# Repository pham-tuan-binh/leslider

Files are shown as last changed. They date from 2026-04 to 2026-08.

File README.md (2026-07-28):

<h1 align="center">LeSlider</h1>

<p align="center">
  
  
  
  
  
</p>

<p align="center">
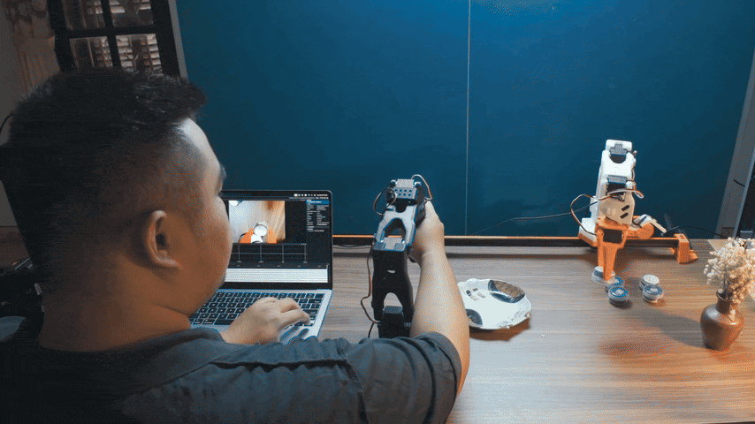
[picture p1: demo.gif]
leslider rig running
  
</p>

<p align="center"><b>Mount an SO-101 on a 7th-motor slider.</b></p>

One teleop mode ships for the full rig: the SO-101 leader mirrors the follower
arm (including the base), while the keyboard drives the linear slider. Optional
cameras on the leader feed Rerun when you use `uv run leslider-teleoperate`. Print the
parts, run `uv sync`, and you have a 7-DOF arm with linear travel that
records datasets and runs policies the same way a stock SO-101 does.

The slider ships in two flavors. The default `so101_slider_follower` drives the
slider in **velocity** mode (`slider.vel`, continuous rotation). A second variant,
`so101_slider_pos_follower`, drives it in **extended (multi-turn) position** mode so
the slider becomes a unified normalized `slider.pos` joint just like the arm — see
[section 10](#10-position-mode-slider-extended-position).

---

## Build flow

1. [Bill of Materials](#1-bill-of-materials): what to buy
2. [3D-printed parts](#2-3d-printed-parts): what to print
3. [Assembly](#3-assembly): wiring and mounting
4. [Install the plugins](#4-install-the-plugins)
5. [Set the slider motor ID](#5-set-the-slider-motor-id)
6. [Calibrate](#6-calibrate)
7. [Run it](#7-run-it): full-rig teleop and live view
8. [Record datasets](#8-record-datasets)
9. [Config reference](#9-config-reference)
10. [Position-mode slider (extended position)](#10-position-mode-slider-extended-position)
11. [Troubleshooting](#11-troubleshooting)

---

## 1. Bill of Materials

Parts you need **in addition to a stock SO-101 kit**. The kit already ships
the six arm STS3215s, brackets, gripper, USB-to-TTL adapter, 12 V PSU, and
cabling, all of which the slider rig reuses.

| Item | Qty | Notes |
| --- | --- | --- |
| [STS3215 Feetech servo](https://www.waveshare.com/wiki/ST3215_Servo) (slider drive) | 1 | same model as the arm motors, shares the SO-101 bus. Bus cable for the slider is included with the servo. |
| [2020 V-slot aluminum extrusion](https://vi.aliexpress.com/item/1005004784760394.html) | 1 | any length sized to your reach (300 to 500 mm is typical) |
| [Gantry plate with V-wheels](https://vi.aliexpress.com/i/32985227943.html?gatewayAdapt=glo2vnm) | 1 | rides the 2020 extrusion as the carriage |
| M3 bolts, 20 mm or longer | 4 | |
| M5 bolts, 10 mm or longer, plus matching M5 nuts | 2 sets | |
| M5 bolts (12 to 16 mm), plus M5 drop-in T-nuts sized for the 2020 V-slot | 2 sets | mounts the legs to the extrusion. M5 is the standard thread for 2020 T-nuts. |

---

## 2. 3D-printed parts

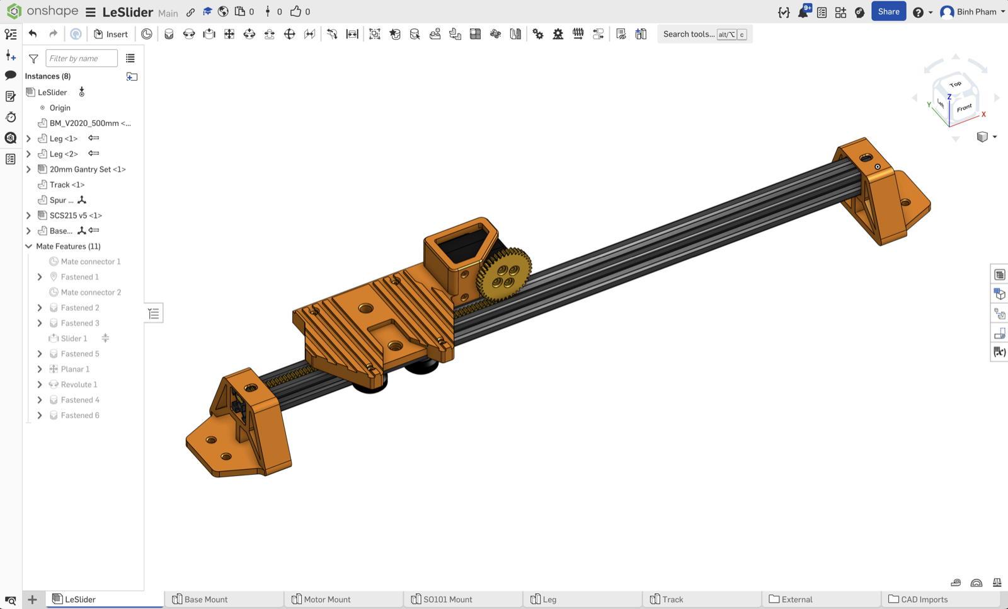
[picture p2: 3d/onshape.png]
Onshape model


Source CAD lives on [Onshape](https://cad.onshape.com/documents/7799de322e403a9ba91b0f22/w/05147a3d6feb75b69c2b0fa5/e/832d406a94d20085fd4bee6e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),
where you can spin the assembly, take measurements, or fork it for your own
extrusion length, motor mount, or leg geometry. Exported printable files
live in `3d/`.

The fastest path is `3d/full_print.3mf`: open it in Bambu Studio (or any
slicer that imports `.3mf`) and the whole plate is laid out for you.
Individual parts also live in `3d/separate_components/` if you want to
slice them on a smaller bed or print them one at a time.

Per rig, you need:

| File | Qty | Notes |
| --- | --- | --- |
| `separate_components/leg.3mf` | 2 | one at each end of the V-slot extrusion |
| `separate_components/base_mount.3mf` | 1 | sits on the gantry plate; holds the SO-101 base and the slider servo |
| `separate_components/pinion.3mf` | 1 | press-fits onto the slider servo's output gear; engages the rack track |
| `separate_components/track.3mf` | as needed | drop-in rack segments for the V-slot. Each segment is 20 mm long; print enough to span your extrusion and trim the last one if it overruns. |

---

## 3. Assembly

1. **Print the parts.** Use `3d/full_print.3mf` for the all-in-one plate, or
   slice the individual files in `3d/separate_components/`. Quantities: 2
   legs, 1 base mount, 1 pinion, plus enough 20 mm track segments to span
   your extrusion (cut the last one to length if it overruns).
2. **Lay the rack track.** Slide the printed track segments into the
   top-facing channel of the V-slot extrusion. They sit directly under
   where the base mount will land, so the slider servo's pinion drops
   straight into the rack.
3. **Slide the gantry plate** onto the V-slot so its V-wheels engage the
   side channels. Do this before the legs go on, so the plate can slide in
   from one open end.
4. **Bolt the legs** to each end of the extrusion. Per leg: one M5 bolt
   through the leg into one drop-in M5 T-nut sitting in the V-slot's side
   channel.
5. **Mount the base plate to the gantry.** The gantry plate has two M5
   holes spaced 20 mm apart; align the base mount over them and secure with
   two M5 bolts plus M5 nuts on the underside.
6. **Bolt the SO-101 base** to the base mount with four M3 bolts (20 mm or
   longer) through the four screw holes in the SO-101's base bracket.
7. **Drop the slider STS3215** into the cutout on the base mount, slide the
   printed pinion onto the servo's output gear so it engages the rack
   track, and secure the servo with the screws that ship in its package.
8. **Daisy-chain the slider** onto the SO-101 bus: unplug the cable that
   runs from the base yaw to the USB-TTL controller, plug it into the slider
   STS3215, then run a new cable from the slider to the controller. The
   order on the bus is base yaw → slider → controller. All seven motors share
   one bus back to the host; only the IDs matter for addressing.
9. **Power.** Use the same power supply that comes with your SO101.

---

## 4. Install the plugins

This repo is a [uv](https://docs.astral.sh/uv/) workspace: the root
`pyproject.toml` lists each workspace package explicitly, so a single `uv sync`
installs `lerobot` along with every workspace package (robot plugin, teleop
plugin, and `leslider_teleoperate`) editable into one
shared `.venv`.

```bash
git clone https://github.com/pham-tuan-binh/leslider
cd leslider
uv sync
```

That's it. There is nothing on PyPI for these plugins; the workspace is the
only install path. Run lerobot CLIs through `uv run` so they pick up the
workspace venv automatically:

```bash
uv run lerobot-teleoperate ...
uv run lerobot-calibrate ...
uv run lerobot-record ...
```

Or activate the venv once per shell with `source .venv/bin/activate` and
call the same commands directly. Editing any file under `packages/*/src/`
takes effect on the next import; no re-sync needed.

LeRobot's plugin loader picks up the packages by name prefix
(`lerobot_robot_*` / `lerobot_teleoperator_*`), so once the venv is active you
should see `so101_slider_follower` and `so101_with_slider_leader` (velocity mode),
plus `so101_slider_pos_follower` and `so101_with_slider_pos_leader` (extended-position
mode), as `--robot.type` / `--teleop.type` choices on every CLI invocation.

For teleoperation with **follower plus leader camera streams** in Rerun, use
`uv run leslider-teleoperate` (same flags as `uv run lerobot-teleoperate`, plus it merges
`teleop.cameras` into the logged observation). Plain `uv run lerobot-teleoperate` only
shows the robot's own `robot.cameras`.

### Find your serial ports

LeRobot ships a port-finder. Unplug the arm it asks about, press ENTER,
plug it back in. Run it once per arm:

```bash
uv run lerobot-find-port
```

Note the paths it prints (`/dev/tty.usbmodem...` on macOS,
`/dev/ttyACM...` on Linux). You'll paste them into the configs below or
pass them on the command line.

### Quick runs with a config file

Every LeRobot CLI accepts `--config_path=<file.yaml>` (parsed by
[draccus](https://github.com/dlwh/draccus)), so once you write a YAML
profile you stop retyping flags. The repo ships ready-made profiles in
`configs/`:

| Profile | What it runs |
| --- | --- |
| `configs/teleop_full_rig.yaml` | SO-101 leader mirrors arm; arrows drive slider (velocity) |
| `configs/calibrate_follower.yaml` | Calibrate the SO-101 + slider follower (velocity) |
| `configs/calibrate_leader.yaml` | Calibrate the stock SO-101 leader |
| `configs/record.yaml` | Record a dataset with the full rig |
| `configs/teleop_full_rig_pos.yaml` | Extended-position rig; arrows drive `slider.pos` |
| `configs/calibrate_follower_pos.yaml` | Calibrate the extended-position follower |

Edit each profile once with your ports and calibration IDs, then:

```bash
uv run lerobot-teleoperate --config_path=configs/teleop_full_rig.yaml
uv run leslider-teleoperate --config_path=configs/teleop_full_rig.yaml
uv run lerobot-calibrate   --config_path=configs/calibrate_follower.yaml
uv run lerobot-calibrate   --config_path=configs/calibrate_leader.yaml
uv run lerobot-record      --config_path=configs/record.yaml
```

Override any field at the CLI for a one-off:

```bash
uv run lerobot-teleoperate --config_path=configs/teleop_full_rig.yaml \
    --robot.port=/dev/tty.usbmodemSOMETHINGELSE
```

The long-form invocations in the sections below show exactly which flags
each profile sets, in case you need to tweak.

---

## 5. Set the slider motor ID

The slider motor must live on a Feetech ID outside 1..6 (default: 7). The
upstream `lerobot-setup-motors` rejects our `so101_slider_follower` type
(its device whitelist is hardcoded), so the repo ships a small wrapper:

```bash
uv run scripts/setup_slider_motor.py \
    --port=/dev/tty.usbmodemFOLLOWER \
    --slider-id=7
```

Connect **only the slider motor** to the controller before pressing ENTER.
The script opens a minimal bus with just the slider so no other motors are
scanned or disturbed.

After that, daisy-chain everything back together.

---

## 6. Calibrate

Only the arm joints need calibration. The slider runs in continuous-rotation
velocity mode and is skipped.

```bash
uv run lerobot-calibrate \
    --robot.type=so101_slider_follower \
    --robot.port=/dev/tty.usbmodemXXXX \
    --robot.id=my_arm
```

This is the stock SO-101 calibration (middle pose, range-of-motion sweep)
against IDs 1..6. The result lands in
`~/.cache/huggingface/lerobot/calibration/robots/so101_slider_follower/my_arm.json`.

If you also use the SO-101 leader arm for teleop, calibrate it once:

```bash
uv run lerobot-calibrate \
    --teleop.type=so101_leader \
    --teleop.port=/dev/tty.usbmodemLEADER \
    --teleop.id=my_leader
```

---

## 7. Run it

Use `so101_with_slider_leader`. All six leader joints, **including**
`shoulder_pan`, are copied to the follower as `*.pos` goals. The linear slider
is driven only from the keyboard as `slider.vel` (same feel as the old
keyboard-only mode).

```bash
uv run lerobot-teleoperate \
    --robot.type=so101_slider_follower \
    --robot.port=/dev/tty.usbmodemFOLLOWER \
    --robot.id=my_arm \
    --teleop.type=so101_with_slider_leader \
    --teleop.port=/dev/tty.usbmodemLEADER \
    --teleop.id=my_leader
```

| Key | Effect |
| --- | --- |
| Leader arm | Mirrors the follower (base, lift, elbow, wrist, gripper). |
| Left / Right arrow | Hold to run the slider negative / positive at the current cruise speed. |
| Up / Down arrow | Tap to raise / lower cruise speed (`speed_increment`, bounded). |
| Space | Hold to command zero slider velocity (emergency stop). |
| ESC | Disconnect |

### Live view: follower + teleop cameras in Rerun

When you run `uv run lerobot-teleoperate` with `display_data: true` in the config (or
`--display_data=true`) it logs the robot observation only. To also stream
**leader-side** USB cameras, run the bundled wrapper and add `teleop.cameras`
in YAML (same shape as `robot.cameras`):

Set `display_data: true` in `configs/teleop_full_rig.yaml` (top level), or pass
`--display_data=true` on the CLI to override.

```bash
uv run leslider-teleoperate --config_path=configs/teleop_full_rig.yaml
```

Uncomment `robot.cameras` / `teleop.cameras` in `configs/teleop_full_rig.yaml` as needed.
Follower cameras (`robot.cameras`) show up as `observation.<name>` everywhere.
`teleop.cameras` is only merged when you use **`uv run leslider-teleoperate`** with
`display_data: true` (Rerun under `observation.teleop.<name>`). **`uv run lerobot-record`**
does not read teleop cameras—see [section 8](#8-record-datasets): put extra USB views on
`robot.cameras` if you want them in the dataset.

---

## 8. Record datasets

Same `uv run lerobot-record` invocation as a stock SO-101, just point at the new
robot type and `so101_with_slider_leader`:

```bash
uv run lerobot-record \
    --robot.type=so101_slider_follower \
    --robot.port=/dev/tty.usbmodemFOLLOWER \
    --robot.id=my_arm \
    --teleop.type=so101_with_slider_leader \
    --teleop.port=/dev/tty.usbmodemLEADER \
    --teleop.id=my_leader \
    --dataset.repo_id=$USER/leslider_demo \
    --dataset.num_episodes=5 \
    --dataset.single_task="slide and grab"
```

The dataset's action space includes `slider.vel`; observations include
`slider.pos` and `slider.vel` alongside the six arm joints.

### Recording with cameras

`uv run lerobot-record` only stores what comes from **`robot.get_observation()`**, so every
camera you want in the dataset must be listed under **`robot.cameras`** in
`configs/record.yaml` (same OpenCV / RealSense / ZMQ entries as upstream LeRobot).
Use `uv run lerobot-find-cameras` to pick `index_or_path` values.

A camera physically mounted on the **leader** still goes in **`robot.cameras`**: it is
just another USB device on the host; name it e.g. `leader_wrist` so it appears as
`observation.leader_wrist` in the dataset. **`teleop.cameras`** is for live Rerun with
`uv run leslider-teleoperate` only and is **not** written by `uv run lerobot-record`.

---

## 9. Config reference

### `SO101SliderFollowerConfig`

Inherits from `SOFollowerConfig` (port, cameras, `max_relative_target`,
`use_degrees`, `disable_torque_on_disconnect`) and adds:

| Field | Default | Description |
| --- | --- | --- |
| `slider_id` | `7` | Feetech bus ID for the slider motor. Must not be in 1..6. Validated at construction. |
| `slider_max_velocity` | `3000`  | Clamp applied to `slider.vel` before writing `Goal_Velocity` (raw sign-magnitude ticks/s). |

### `SO101WithSliderLeaderConfig`

| Field | Default | Description |
| --- | --- | --- |
| `port` | required | Serial port of the SO-101 leader arm. |
| `use_degrees` | `True` | Leader joint units (gripper stays 0..100). |
| `cameras` | `{}` | Optional dict of `CameraConfig` entries for `uv run leslider-teleoperate` + Rerun. |
| `cruise_velocity`  | `1500` | Raw ticks/s magnitude when Left/Right is held. |
| `speed_increment`  | `250` | Cruise change per Up/Down tap. |
| `min_velocity` | `100` | Lower bound of cruise trim. |
| `max_velocity` | `3000` | Upper bound of cruise trim. |
| `invert_direction` | `False` | Swap Left ↔ Right for `slider.vel` if the slider is mounted flipped. |

---

## 10. Position-mode slider (extended position)

The default rig drives the slider in velocity mode: you steer it with `slider.vel`
and the slider never reports an absolute position. The **position-mode** variant
instead runs the slider's STS3215 in **extended (multi-turn) position** mode, so the
slider becomes a normalized `slider.pos` joint in `0..100` — control and dataset
layout are then fully unified with the six arm joints (every joint is a `.pos`).

Use these types in place of the velocity ones:

| Velocity mode (default) | Position mode (this section) |
| --- | --- |
| `so101_slider_follower` | `so101_slider_pos_follower` |
| `so101_with_slider_leader` | `so101_with_slider_pos_leader` |

### How the range works

The slider's travel maps to a fixed lower bound and a calibrated upper cap: the
range is **always `[-28762, cap]`** in raw multi-turn ticks. `range_min` is a fixed
constant (`slider_range_min`, default `-28762`, near the most-negative multi-turn
position) that maps to `slider.pos = 0`; only the upper cap is discovered during
calibration and maps to `slider.pos = 100`. Multi-turn is enabled by zeroing the
STS3215 angle limits (`configure()` does this on every connect); software
normalization then maps `[-28762, cap] → [0, 100]`.

### Calibrate

```bash
uv run lerobot-calibrate --config_path=configs/calibrate_follower_pos.yaml
# or:
uv run lerobot-calibrate \
    --robot.type=so101_slider_pos_follower \
    --robot.port=/dev/tty.usbmodemFOLLOWER \
    --robot.id=my_arm
```

The six arm joints use the **stock SO-101 procedure** (center pose, then the
range-of-motion sweep with `wrist_roll` kept at `0..4095`). The slider adds two
steps at the end:

1. **Drive to minimum.** A prompt warns the slider is about to move; press ENTER and
   the motor drives under torque to `-28762` (the physical bottom, `slider.pos = 0`).
   Wait for it to bottom out, then press ENTER.
2. **Free-roll to the cap.** Torque releases so you can push the slider by hand to its
   upper limit (`slider.pos = 100`); press ENTER to record that encoder value as the cap.

Calibration is saved (all seven joints) under
`~/.cache/huggingface/lerobot/calibration/robots/so101_slider_pos_follower/my_arm.json`.

### Run it

```bash
uv run leslider-teleoperate --config_path=configs/teleop_full_rig_pos.yaml
# or the long form:
uv run lerobot-teleoperate \
    --robot.type=so101_slider_pos_follower \
    --robot.port=/dev/tty.usbmodemFOLLOWER \
    --robot.id=my_arm \
    --teleop.type=so101_with_slider_pos_leader \
    --teleop.port=/dev/tty.usbmodemLEADER \
    --teleop.id=my_leader
```

The leader has no physical slider, so the keyboard integrates a position target:

| Key | Effect |
| --- | --- |
| Leader arm | Mirrors the follower (base, lift, elbow, wrist, gripper). |
| Left / Right arrow | Hold to ramp `slider.pos` toward `0` / `100` by `slider_step` per loop. |
| Up / Down arrow | Tap to raise / lower `slider_step` (bounded by `min_step` / `max_step`). |
| Space | Hold to freeze the slider target. |
| ESC | Disconnect |

> **Heads up:** `slider.pos = 0` is the deep-retract extreme (`-28762`), not the
> slider's rest pose, so the resting position reads as a positive value. On connect
> the teleop's `initial_position` (default `0.0`) is commanded immediately, which
> drives the slider toward the bottom — set it to roughly the slider's resting
> `slider.pos`, and keep `max_relative_target` set to cap per-step motion.

Datasets recorded with this variant carry `slider.pos` (not `slider.vel`) in both the
action and observation space, alongside the six arm `.pos` joints.

### Why the slider is speed-capped

`slider_goal_speed` defaults to `2000` ticks/s, and removing the cap makes travel
**slower**, not faster. With `Goal_Velocity = 0` the position controller commands full
PWM, `Present_Load` pegs at 1000, and once load stays above `Overload_Torque` (80%) for
`Protection_Time` (~2s) the servo clamps output to `Protective_Torque` (20%) for the
remainder of the move. Measured over a 5.7-turn stroke:

| `Goal_Velocity` | time | load (max / mean) | overload bit |
| --- | --- | --- | --- |
| `2000` | 11.9s | 775 / 669 | clean |
| `2400` | 10.0s | 857 / 790 | clean, but no margin |
| `2800` | 38.1s | 1000 / 239 | trips at ~2s |
| `0` (uncapped) | 38s+ | 1000 / 239 | trips at ~2s |

`2000` is the default because `2400`'s mean load sits ~10 counts under the trip
threshold, so any extra friction tips it over -- and a trip costs roughly 4x the time.
The cap is applied in the calibration path as well as `configure()`, since `calibrate()`
runs first and its drive-to-minimum is the longest move the slider ever makes.

### Config reference

**`SO101SliderPosFollowerConfig`** — inherits `SOFollowerConfig` (port, cameras,
`max_relative_target`, `use_degrees`, `disable_torque_on_disconnect`) and adds:

| Field | Default  | Description |
| --- | --- | --- |
| `slider_id` | `7` | Feetech bus ID for the slider motor. Must not be in 1..6. |
| `slider_range_min` | `-28762` | Fixed raw lower bound mapped to `slider.pos = 0`. Only the upper cap is calibrated. |
| `slider_goal_speed`| `2000` | Travel-speed cap (raw ticks/s) in position mode via `Goal_Velocity`. `0` = uncapped, which is *slower*: uncapped moves trip the servo's overload protection after ~2s and drop to 20% torque. See below. |
| `read_current` | `False`  | Adds `{motor}.current` (raw mA) to each observation for all seven motors. |

**`SO101WithSliderPosLeaderConfig`**

| Field | Default  | Description |
| --- | --- | --- |
| `port` | required | Serial port of the SO-101 leader arm. |
| `use_degrees` | `True` | Leader joint units (gripper stays 0..100). |
| `cameras` | `{}` | Optional `CameraConfig` entries for `uv run leslider-teleoperate` + Rerun.  |
| `slider_step` | `1.0` | Normalized units added to `slider.pos` per `get_action()` while Left/Right held. |
| `step_increment` | `0.25` | `slider_step` change per Up/Down tap. |
| `min_step` | `0.1` | Lower bound of the step trim. |
| `max_step` | `5.0` | Upper bound of the step trim. |
| `initial_position` | `0.0` | Starting `slider.pos` target on connect (`0` = fixed minimum). |
| `invert_direction` | `False`  | Swap Left ↔ Right if the slider is mounted flipped. |

---

## 11. Troubleshooting

- **`ValueError: slider_id=… collides with an SO-101 arm motor`**: pick a
  slider ID outside 1..6 (default is 7).
- **Slider doesn't move.** Check the slider is in velocity mode after
  `configure()`: `bus.read("Operating_Mode", "slider")` should return `1`. If
  torque is off, confirm `disable_torque_on_disconnect` from the previous
  session didn't leave it disabled.
- **Arrow keys do nothing / teleop won't connect.** `pynput` is required; on
  Linux without `DISPLAY` it may not load. Run inside a graphical session (or
  over X/Wayland forwarding).
- **Slider kicks on startup.** The follower writes `Goal_Velocity = 0` inside
  `configure()` _before_ re-enabling torque. If you still see motion, confirm
  the previous session's `disconnect()` zeroed the velocity (it tries to,
  inside a `try/except` so other disconnect work still runs).
- **Leader wrist roll barely moves / follower wrist roll shoots to a stop.**
  Stock SO-101 calibration does **not** record a separate range for
  `wrist_roll`: it keeps a synthetic encoder span `0..4095` and relies on the
  homing step when you saved the “middle” pose. If that step was wrong, or the
  servo’s **Min_Position_Limit / Max_Position_Limit** (Feetech EEPROM) are
  tighter than the full span, goals from LeRobot (in **degrees**, then mapped
  to raw ticks) can clamp against a limit and look like “always runs to the
  end.” Re-run `uv run lerobot-calibrate` with **`c`** for a fresh calibration,
  center **all** joints carefully on ENTER, then check the wrist roll servo in
  the manufacturer tool: **position mode**, torque, ID **5**, and limits
  spanning the real range. When testing by hand, compare **raw** Goal_Position
  (0–4095) with **normalized** degrees from LeRobot—they are not the same number.

## License

Apache-2.0. See [LICENSE](LICENSE).

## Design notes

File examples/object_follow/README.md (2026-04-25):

# object_follow

A self-contained example: an Ultralytics YOLO detector pulls bounding boxes out
of a camera feed, and a PID loop converts the horizontal pixel error of a
tracked object into a slider velocity for the SO-101 slider robot. The slider
follows the object so it stays centered in the frame.

```
camera frame ──► YOLO detect+track ──► pixel error (x_target - x_center)
                                              │
                                              ▼
                                          PID loop  ──►  slider.vel  ──►  SO101SliderFollower
```

## Setup with uv

From this directory:

```bash
uv sync
```

That installs `lerobot`, `ultralytics`, `opencv-python`, and the local
`lerobot_robot_so101_slider` package in editable mode (it's referenced by
relative path in `pyproject.toml`).

The first run will download a YOLO weights file (default `yolo11n.pt`) into
this directory.

## Run it

```bash
uv run object-follow \
    --robot.port=/dev/tty.usbmodemFOLLOWER \
    --robot.id=my_arm \
    --camera-index=0 \
    --target-class=person
```

Press `q` in the preview window or `Ctrl-C` in the terminal to exit; the
slider is zeroed and the robot disconnected on the way out.

### Useful flags

| Flag | Default | Notes |
| ---- | --- | ----- |
| `--robot.port` | required | Serial port of the SO-101 follower (with slider motor on the bus). |
| `--robot.id` | required | Calibration ID — the same one passed to `lerobot-calibrate`. |
| `--camera-index` | `0` | OpenCV camera index. |
| `--model` | `yolo11n.pt` | Any Ultralytics-compatible weights file. |
| `--target-class` | `person` | Class name (or numeric COCO id) the slider tracks. |
| `--conf` | `0.35` | Minimum detection confidence. |
| `--kp` / `--ki` / `--kd` | `6.0 / 0.0 / 0.4` | PID gains, mapping pixel error → ticks/s. |
| `--deadzone-px` | `25` | Inside this pixel band the slider commands zero. |
| `--max-velocity` | `2500` | Hard clamp on `slider.vel` (raw ticks/s). |
| `--invert` | off | Flip slider direction if the camera is mounted backwards. |
| `--no-preview` | off | Run headless (skip the OpenCV window). |

### What can it detect?

The default model (`yolo11n.pt`) is YOLO11-nano pretrained on COCO, so it
recognizes 80 classes. A few useful ones for this rig:

- **People & animals** — person, bird, cat, dog, horse, sheep, cow, elephant, bear, zebra, giraffe
- **Vehicles** — bicycle, car, motorcycle, airplane, bus, train, truck, boat
- **Sports** — frisbee, sports ball, skateboard, surfboard, tennis racket, baseball bat/glove
- **Kitchen / desk** — bottle, wine glass, cup, fork, knife, spoon, bowl, cell phone, laptop, mouse, keyboard, book, scissors
- **Food** — banana, apple, sandwich, orange, broccoli, carrot, pizza, donut, cake
- **Furniture** — chair, couch, bed, dining table, potted plant
- **Misc** — backpack, umbrella, handbag, tie, suitcase, teddy bear, clock, vase

Pass any of these names (or the numeric COCO id) to `--target-class`. Full
list with `python -c "from ultralytics import YOLO; print(YOLO('yolo11n.pt').names)"`.
For something outside COCO, swap `--model` for a custom-trained `.pt` — the
rest of the pipeline doesn't care.

## How it works

1. **Detection** — `ultralytics.YOLO` runs `model.track()` per frame so a
   single object keeps its identity across frames. We pick the highest-confidence
   detection of `target-class`; if it has a tracker id we lock onto it and
   prefer its future detections to avoid jumping to other objects of the same
   class.
2. **Error** — `error_px = x_target - frame_width / 2`. Positive means the
   object is right of center.
3. **PID** — gains map pixel error to `slider.vel` ticks/s. The derivative
   term is low-pass-filtered against measurement noise from jittery boxes.
4. **Output** — clamped to `±max-velocity`, sign-flipped if `--invert`,
   sent through `SO101SliderFollower.send_action({"slider.vel": v})`.

When no target is visible the PID is reset and `slider.vel = 0` so the slider
coasts to a stop instead of running away on stale state.

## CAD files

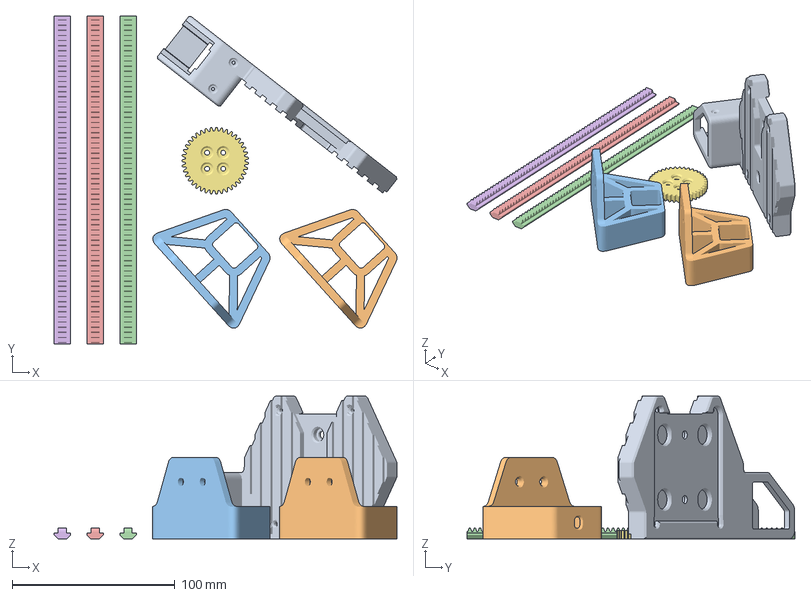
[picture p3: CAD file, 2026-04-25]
3d/full_print.3mf
210.5 x 201.1 x 87.6 mm
Base Mount
Leg x 2
Track x 3
Pinion

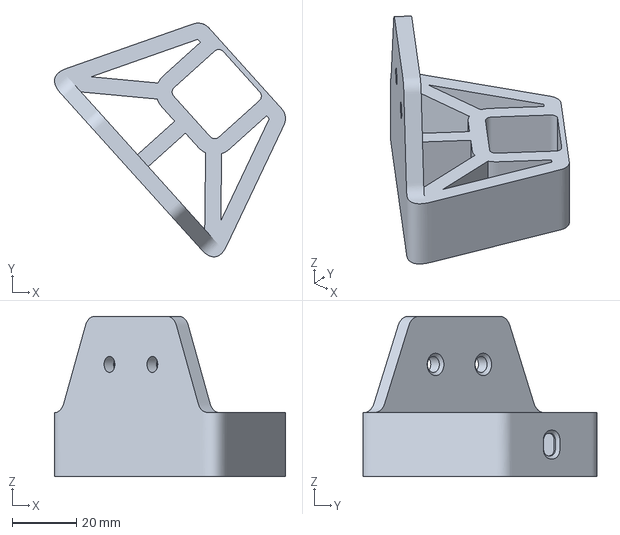
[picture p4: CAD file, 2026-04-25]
3d/separate_components/leg.3mf
72.0 x 72.9 x 50.0 mm

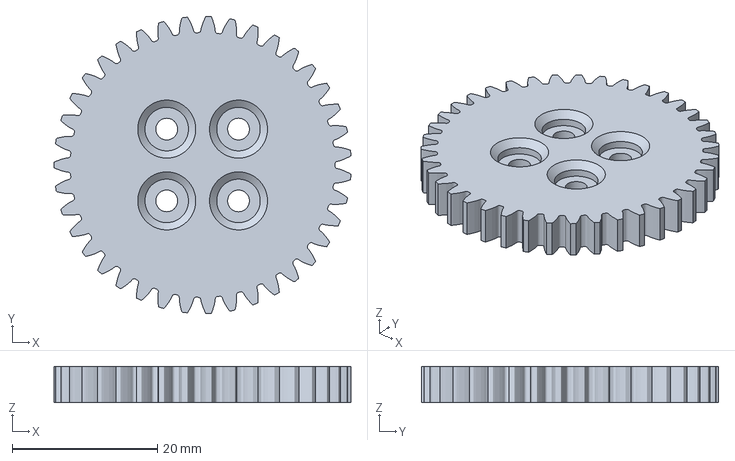
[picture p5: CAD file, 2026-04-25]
3d/separate_components/pinion.3mf
41.0 x 41.0 x 5.00 mm

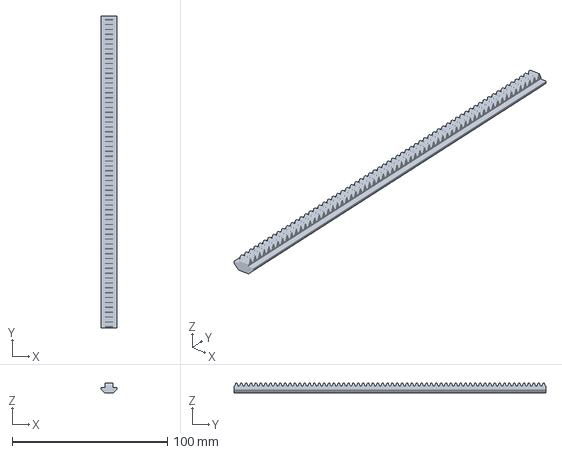
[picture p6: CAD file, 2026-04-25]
3d/separate_components/track.3mf
10.2 x 201.1 x 6.66 mm

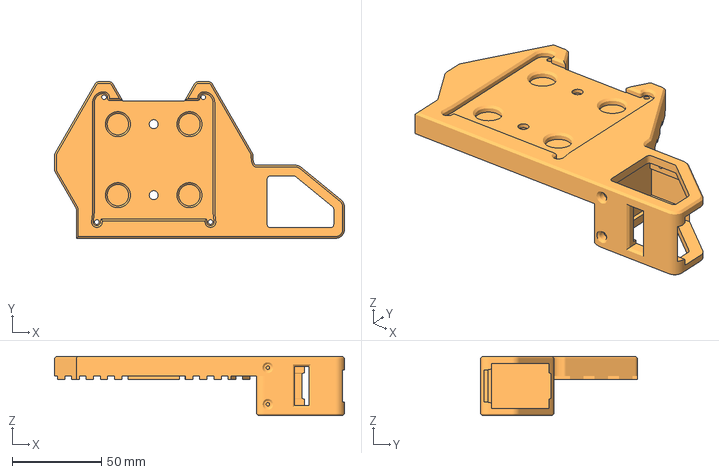
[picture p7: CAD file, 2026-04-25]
3d/separate_components/base_mount.3mf
162.1 x 87.6 x 33.1 mm

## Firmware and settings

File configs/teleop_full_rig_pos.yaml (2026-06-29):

# Position-mode rig: SO-101 leader mirrors the follower arm (base included);
# arrow keys drive the slider as a unified normalized position (slider.pos).
# The slider's STS3215 runs in extended (multi-turn) position mode.
#
#   uv run leslider-teleoperate --config_path=configs/teleop_full_rig_pos.yaml
#
# Controls: Left/Right ramp slider.pos toward 0/100, Up/Down trim the step,
# Space freezes the slider target, ESC quits.

robot:
  type: so101_slider_pos_follower
  port: /dev/tty.usbmodemFOLLOWER
  id: my_arm
  slider_id: 7
  # slider_goal_speed: 0   # raw ticks/s travel-speed cap in position mode (0 = full speed)
  # Example follower-mounted camera (shown as observation.<name>):
  # cameras:
  #   front:
  #     type: opencv
  #     index_or_path: 0
  #     width: 640
  #     height: 480
  #     fps: 30

teleop:
  type: so101_with_slider_pos_leader
  port: /dev/tty.usbmodemLEADER
  id: my_leader
  slider_step: 1.0
  step_increment: 0.25
  min_step: 0.1
  max_step: 5.0
  initial_position: 0.0
  invert_direction: false
  # Optional leader-side camera(s) for Rerun when display_data is true:
  # cameras:
  #   leader_wrist:
  #     type: opencv
  #     index_or_path: 1
  #     width: 640
  #     height: 480
  #     fps: 30

display_data: false
# display_ip: null
# display_port: null
# display_compressed_images: false

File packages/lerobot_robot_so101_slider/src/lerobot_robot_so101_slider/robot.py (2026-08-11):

import logging
import time
from functools import cached_property

from lerobot.cameras import make_cameras_from_configs
from lerobot.motors import Motor, MotorCalibration, MotorNormMode
from lerobot.motors.feetech import FeetechMotorsBus, OperatingMode
from lerobot.robots.robot import Robot
from lerobot.robots.utils import ensure_safe_goal_position
from lerobot.lerobot_types import RobotAction, RobotObservation
from lerobot.utils.decorators import check_if_already_connected, check_if_not_connected

from .config import SO101SliderFollowerConfig

logger = logging.getLogger(__name__)

SLIDER = "slider"
ARM_MOTORS = ("shoulder_pan", "shoulder_lift", "elbow_flex", "wrist_flex", "wrist_roll", "gripper")
ALL_MOTORS = (*ARM_MOTORS, SLIDER)


class SO101SliderFollower(Robot):
    """SO-101 arm mounted on a linear slider driven by an extra STS3215.

    All seven motors share one Feetech bus. The six arm motors behave exactly
    like a stock SO-101 (position mode, normalized .pos actions). The slider
    motor is placed in wheel/velocity mode so it can turn continuously; it
    accepts raw tick/s velocity commands via the `slider.vel` action key.
    """

    config_class = SO101SliderFollowerConfig
    name = "so101_slider_follower"

    def __init__(self, config: SO101SliderFollowerConfig):
        super().__init__(config)
        self.config = config

        if config.slider_id in range(1, 7):
            raise ValueError(
                f"slider_id={config.slider_id} collides with an SO-101 arm motor (IDs 1..6)."
            )

        arm_norm = MotorNormMode.DEGREES if config.use_degrees else MotorNormMode.RANGE_M100_100
        self.bus = FeetechMotorsBus(
            port=self.config.port,
            motors={
                "shoulder_pan": Motor(1, "sts3215", arm_norm),
                "shoulder_lift": Motor(2, "sts3215", arm_norm),
                "elbow_flex": Motor(3, "sts3215", arm_norm),
                "wrist_flex": Motor(4, "sts3215", arm_norm),
                "wrist_roll": Motor(5, "sts3215", arm_norm),
                "gripper": Motor(6, "sts3215", MotorNormMode.RANGE_0_100),
                # Slider is commanded by raw velocity; norm_mode is unused because
                # Goal_Velocity/Present_Velocity are not in the normalized-register list.
                SLIDER: Motor(config.slider_id, "sts3215", MotorNormMode.RANGE_M100_100),
            },
            calibration=self.calibration,
        )
        self.cameras = make_cameras_from_configs(config.cameras)

    @property
    def _motors_ft(self) -> dict[str, type]:
        ft = {f"{motor}.pos": float for motor in ARM_MOTORS}
        # Slider is in wheel/velocity mode; Present_Position wraps and is not
        # meaningful as an absolute position, so only velocity is reported.
        ft[f"{SLIDER}.vel"] = float  # raw ticks/s from Present_Velocity
        if self.config.read_current:
            for motor in ALL_MOTORS:
                ft[f"{motor}.current"] = float  # raw mA, read from Present_Current
        return ft

    @property
    def _cameras_ft(self) -> dict[str, tuple]:
        return {
            cam: (self.config.cameras[cam].height, self.config.cameras[cam].width, 3)
            for cam in self.cameras
        }

    @cached_property
    def observation_features(self) -> dict[str, type | tuple]:
        return {**self._motors_ft, **self._cameras_ft}

    @cached_property
    def action_features(self) -> dict[str, type]:
        return {f"{motor}.pos": float for motor in ARM_MOTORS} | {f"{SLIDER}.vel": float}

    @property
    def is_connected(self) -> bool:
        return self.bus.is_connected and all(cam.is_connected for cam in self.cameras.values())

    @property
    def is_calibrated(self) -> bool:
        # Only the arm joints are calibrated. The slider is a continuous-rotation
        # motor driven in velocity mode, so its position calibration is meaningless;
        # we skip it instead of writing synthetic limits.
        on_motor = self.bus.read_calibration()
        cached = self.calibration
        if set(cached) != set(ARM_MOTORS):
            return False
        for motor in ARM_MOTORS:
            if motor not in on_motor:
                return False
            if (
                cached[motor].range_min != on_motor[motor].range_min
                or cached[motor].range_max != on_motor[motor].range_max
                or cached[motor].homing_offset != on_motor[motor].homing_offset
            ):
                return False
        return True

    @check_if_already_connected
    def connect(self, calibrate: bool = True) -> None:
        self.bus.connect()
        if not self.is_calibrated and calibrate:
            logger.info(
                "Mismatch between calibration values in the motor and the calibration file or no calibration file found"
            )
            self.calibrate()

        for cam in self.cameras.values():
            cam.connect()

        self.configure()
        logger.info(f"{self} connected.")

    def calibrate(self) -> None:
        """Calibrate the arm joints the same way as SO-101. The slider motor is
        continuous-rotation so we skip homing/range discovery for it and write
        a full-range pass-through calibration instead."""
        if self.calibration:
            user_input = input(
                f"Press ENTER to use provided calibration file associated with the id {self.id}, "
                f"or type 'c' and press ENTER to run calibration: "
            )
            if user_input.strip().lower() != "c":
                logger.info(f"Writing calibration file associated with the id {self.id} to the motors")
                self.bus.write_calibration(self.calibration)
                return

        logger.info(f"\nRunning calibration of {self}")
        self.bus.disable_torque()
        # Only put the arm in position mode for calibration; the slider stays as-is
        # (configure() will set it to velocity mode afterwards).
        for motor in ARM_MOTORS:
            self.bus.write("Operating_Mode", motor, OperatingMode.POSITION.value)

        input(f"Move {self} arm to the middle of its range of motion and press ENTER....")
        homing_offsets = self.bus.set_half_turn_homings(list(ARM_MOTORS))

        full_turn_motor = "wrist_roll"
        unknown_range_motors = [m for m in ARM_MOTORS if m != full_turn_motor]
        print(
            f"Move all arm joints except '{full_turn_motor}' sequentially through their "
            "entire ranges of motion.\nRecording positions. Press ENTER to stop..."
        )
        range_mins, range_maxes = self.bus.record_ranges_of_motion(unknown_range_motors)
        range_mins[full_turn_motor] = 0
        range_maxes[full_turn_motor] = 4095
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

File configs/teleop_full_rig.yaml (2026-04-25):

# Full SO-101 leader: arm mirrors follower (base included); arrows drive the slider.
# Rerun + console telemetry: set display_data: true below (or pass --display_data=true on the CLI).
# Live view with teleop cameras needs leslider-teleoperate and teleop.cameras uncommented.
#
#   uv run leslider-teleoperate --config_path=configs/teleop_full_rig.yaml
#
# Stock lerobot-teleoperate still works but only logs robot (follower) cameras in Rerun.

robot:
  type: so101_slider_follower
  port: /dev/tty.usbmodemFOLLOWER
  id: my_arm
  slider_id: 7
  slider_max_velocity: 3000
  # Example follower-mounted camera (shown as observation.<name>):
  # cameras:
  #   front:
  #     type: opencv
  #     index_or_path: 0
  #     width: 640
  #     height: 480
  #     fps: 30

teleop:
  type: so101_with_slider_leader
  port: /dev/tty.usbmodemLEADER
  id: my_leader
  cruise_velocity: 1500
  speed_increment: 250
  min_velocity: 100
  max_velocity: 3000
  invert_direction: false
  # Optional leader-side camera(s) for Rerun when display_data is true and using leslider-teleoperate:
  # cameras:
  #   leader_wrist:
  #     type: opencv
  #     index_or_path: 1
  #     width: 640
  #     height: 480
  #     fps: 30

# Top-level teleop script options (same as lerobot-teleoperate / leslider-teleoperate).
display_data: false
# display_ip: null
# display_port: null
# display_compressed_images: false

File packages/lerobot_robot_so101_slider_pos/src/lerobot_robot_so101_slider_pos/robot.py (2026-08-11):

import logging
import time
from functools import cached_property

from lerobot.cameras import make_cameras_from_configs
from lerobot.motors import Motor, MotorCalibration, MotorNormMode
from lerobot.motors.encoding_utils import encode_sign_magnitude
from lerobot.motors.feetech import FeetechMotorsBus, OperatingMode
from lerobot.robots.robot import Robot
from lerobot.robots.utils import ensure_safe_goal_position
from lerobot.lerobot_types import RobotAction, RobotObservation
from lerobot.utils.decorators import check_if_already_connected, check_if_not_connected

from .config import SO101SliderPosFollowerConfig

logger = logging.getLogger(__name__)

SLIDER = "slider"
ARM_MOTORS = ("shoulder_pan", "shoulder_lift", "elbow_flex", "wrist_flex", "wrist_roll", "gripper")
ALL_MOTORS = (*ARM_MOTORS, SLIDER)

# Multi-turn ("extended position") is enabled by *widening* the angle-limit registers,
# not by zeroing them.
#
# WHY, and why the old recipe worked on some rigs: zeroing both limits is the Feetech
# convention for "unlimited", and genuine STS3215 firmware honours it. A Hiwonder HX-30
# -- a drop-in STS3215 replacement, but not a Feetech part -- does not. On the HX-30,
# Min_Position_Limit = Max_Position_Limit = 0 restricts the allowed range to exactly
# [0, 0], so every Goal_Position except 0 is rejected with bit 4 (angle) of the Status
# register set. The two are hard to tell apart: both report Model_Number 777 and share
# the STS/SMS control table. The observed tell is firmware + Angular_Resolution --
# genuine Feetech read 3.9 / AR=1, the HX-30 reads 3.11 / AR=0.
#
# Widening the limits is verified on BOTH parts, which is why it is unconditional here:
#
#   genuine STS3215 (fw 3.9)   zeroed and widened both accept the full +/-30719 range,
#                              and a driven 2-turn move tracked Present_Position to
#                              ~7959 with no wrap under widened limits.
#   Hiwonder HX-30 (fw 3.11)   zeroed accepts goal 0 only; widened accepts the full
#                              +/-30719 range.
#
# Once bit 4 latches, the servo returns a non-zero error byte on *every* subsequent
# packet -- including plain reads -- and lerobot treats any non-zero error as fatal. A
# single bad goal therefore looks like the whole bus has died.
#
# The limits live in EPROM, so torque must be off (Lock = 0) when writing them.
# Min/Max_Position_Limit are absent from lerobot's sign-magnitude encoding table, so a
# negative lower limit has to be passed pre-encoded: lerobot's serializer rejects raw
# negative ints ("Negative values are not allowed").
#
# Goals up to +/-30719 are accepted and +/-32766 is rejected, so 30719 is the widest safe
# span. Bit 4 of Phase is *not* what gates any of this -- phase 12 and 28 behave
# identically on both parts. It is left set only because it is harmless and was already
# there.
MULTITURN_MAX_TICKS = 30719
MULTITURN_PHASE_BIT = 0x10


class SO101SliderPosFollower(Robot):
    """SO-101 arm on a linear slider, slider driven in extended (multi-turn) position.

    All seven motors share one Feetech bus and are commanded with normalized
    ``.pos`` actions. The slider's STS3215 runs in position mode with multi-turn
    enabled, so the leadscrew can travel several revolutions without the encoder
    wrapping. The lower bound is a fixed constant (``config.slider_range_min``,
    default the most-negative multi-turn position); calibration only records the
    upper limit as ``range_max``. Software normalization then maps that range onto a
    unified ``slider.pos`` in ``0..100`` (0 = fixed minimum, 100 = upper limit).

    Unlike the velocity-mode `so101_slider_follower`, the action and observation
    dicts here are uniform: every joint (including the slider) is a normalized
    ``.pos`` key.
    """

    config_class = SO101SliderPosFollowerConfig
    name = "so101_slider_pos_follower"

    def __init__(self, config: SO101SliderPosFollowerConfig):
        super().__init__(config)
        self.config = config

        if config.slider_id in range(1, 7):
            raise ValueError(
                f"slider_id={config.slider_id} collides with an SO-101 arm motor (IDs 1..6)."
            )

        if abs(config.slider_range_min) > MULTITURN_MAX_TICKS:
            raise ValueError(
                f"slider_range_min={config.slider_range_min} is outside the multi-turn range the "
                f"STS3215 accepts (+/-{MULTITURN_MAX_TICKS} ticks). The servo would reject "
                "Goal_Position and set bit 4 of its Status register."
            )

        arm_norm = MotorNormMode.DEGREES if config.use_degrees else MotorNormMode.RANGE_M100_100
        self.bus = FeetechMotorsBus(
            port=self.config.port,
            motors={
                "shoulder_pan": Motor(1, "sts3215", arm_norm),
                "shoulder_lift": Motor(2, "sts3215", arm_norm),
                "elbow_flex": Motor(3, "sts3215", arm_norm),
                "wrist_flex": Motor(4, "sts3215", arm_norm),
                "wrist_roll": Motor(5, "sts3215", arm_norm),
                "gripper": Motor(6, "sts3215", MotorNormMode.RANGE_0_100),
                # Slider is a normalized 0..100 position joint: 0 = home, 100 = upper limit.
                SLIDER: Motor(config.slider_id, "sts3215", MotorNormMode.RANGE_0_100),
            },
            calibration=self.calibration,
        )
        self.cameras = make_cameras_from_configs(config.cameras)

    @property
    def _motors_ft(self) -> dict[str, type]:
        ft = {f"{motor}.pos": float for motor in ALL_MOTORS}
        if self.config.read_current:
            for motor in ALL_MOTORS:
                ft[f"{motor}.current"] = float  # raw mA, read from Present_Current
        return ft

    @property
    def _cameras_ft(self) -> dict[str, tuple]:
        return {
            cam: (self.config.cameras[cam].height, self.config.cameras[cam].width, 3)
            for cam in self.cameras
        }

    @cached_property
    def observation_features(self) -> dict[str, type | tuple]:
        return {**self._motors_ft, **self._cameras_ft}

    @cached_property
    def action_features(self) -> dict[str, type]:
        return {f"{motor}.pos": float for motor in ALL_MOTORS}

    @property
    def is_connected(self) -> bool:
        return self.bus.is_connected and all(cam.is_connected for cam in self.cameras.values())
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

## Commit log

2026-04-25 Initial commit: SO-101 slider rig + object_follow example
    Three lerobot plugins for an SO-101 mounted on an STS3215-driven slider
    (follower, keyboard slider leader, SO-101 leader with base→slider mapping)
    and an examples/object_follow project that drives the slider via a YOLO
    detector and PID loop.
2026-04-25 Add 3D-printed parts and rewrite assembly for the rack-and-pinion drive
    Drops the previous belt-driven plan in favor of a printed rack track that
    sits in the top channel of the 2020 V-slot, with a printed pinion on the
    slider STS3215 driving the gantry along it. Adds full_print.3mf for a
    single-plate slice and the four individual files (leg, base_mount, pinion,
    track) under separate_components/. Rewrites the BOM to list only the
    hardware needed in addition to a stock SO-101 kit, and updates the
    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
    [base_mount.3mf, full_print.3mf, leg.3mf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]
2026-05-01 fix slider motor setup and wiring instructions
    setup_slider_motor.py now builds a minimal bus with only the slider motor
    so no handshake is attempted against the full arm. README wiring step
    corrects the daisy-chain order (base yaw -> slider -> controller) and
    removes the incorrect "spare port" reference.
2026-05-04 fix keyboard teleop input on Ubuntu and handle device disconnects
    Pump process_input_events() each loop tick so the lerobot keyboard
    teleoperator (d/s/w/a) registers key presses on Ubuntu. Catch
    DeviceNotConnectedError alongside KeyboardInterrupt so unexpected
    disconnects exit cleanly instead of traceback-crashing.
2026-05-06 add opt-in current reading to SO101SliderFollower
    Add `read_current: bool = False` to the config. When enabled, a single
    sync_read("Present_Current") across all 7 motors is appended to every
    observation as `{motor}.current` (raw mA, unsigned 16-bit). Off by default
    to keep existing configs unaffected.
2026-05-06 fix(so101-slider): drop slider.pos from observations, keep slider.vel only
    Slider motor runs in wheel/velocity mode so Present_Position wraps
    continuously and is not a meaningful absolute position. Remove the
    Present_Position read and the slider.pos observation key; report only
    Present_Velocity as slider.vel, which is the only real sensor reading.
    [robot.py]
2026-06-29 feat(slider-pos): add extended-position slider follower + teleop
    Add a position-mode variant of the slider rig where the slider runs in
    extended (multi-turn) position instead of velocity. The slider becomes a
    unified normalized slider.pos joint (0..100), so action/observation layout
    matches the six arm joints.
    - lerobot_robot_so101_slider_pos: so101_slider_pos_follower. Slider in
    multi-turn position mode (angle limits zeroed in configure()); software
    normalization maps a fixed [-28762, cap] range to 0..100. Calibration
    drives the slider to the fixed minimum under torque, then free-rolls by
    hand to record the upper cap. Arm calibration is the stock SO-101 flow.
    - lerobot_teleoperator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
    [calibrate_follower_pos.yaml]
2026-06-29 fix(slider-pos): robust calibration that survives slider failures
    write_calibration pushed the slider's negative multi-turn range_min
    (-28762) into Min_Position_Limit, which the Feetech serializer rejects
    ("Negative values are not allowed"), crashing the final save. The slider
    runs in multi-turn mode where those limit registers must be 0 anyway.
    - Add _write_calibration(): writes only arm motors' limits to the bus and
    caches the full dict (slider included) for software normalization,
    leaving the slider's angle-limit registers to _enable_slider_multiturn().
    - Split calibrate() into _calibrate_arm() / _calibrate_slider() and persist
    the arm calibration to disk immediately after the arm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
    [robot.py]
2026-06-29 fix(slider-pos): set Phase bit 4 to actually enable multi-turn
    Zeroing both angle limits is not enough to put the STS3215 into
    extended/multi-turn mode: bit 4 (0x10) of the Phase register must also
    be set. Without it the servo stayed single-turn and Present_Position
    wrapped at 4095, so slider.pos normalized to ~100 for almost every
    position even though Goal_Position writes still drove the slider to the
    right place.
    _enable_slider_multiturn() now reads Phase and ORs in the bit. It runs
    in configure() on every connect, which is required since the mode is
    not retained across power cycles.
    [robot.py]
2026-07-28 fix(slider-pos): widen angle limits for multi-turn on Hiwonder HX-30
    The slider on the Jetson rig is a Hiwonder HX-30, a drop-in STS3215
    replacement that is not a Feetech part (model 777, firmware 3.11, same
    STS/SMS control table). Its firmware does not implement the zeroed-angle-
    limits convention for multi-turn: with Min_Position_Limit =
    Max_Position_Limit = 0 it restricts the allowed range to exactly [0, 0]
    and rejects every Goal_Position except 0.
    Calibration therefore died on the first slider move with
    RuntimeError: Failed to write 'Goal_Position' on id_=7 with '61530'
    and a blank error description, because the servo sets bit 4 (angle) of
    its Status register and the Feetech SDK's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
    [robot.py]
2026-07-28 docs(slider-pos): record that widened limits are verified on real Feetech too
    Tested the widened-limits recipe against a genuine Feetech STS3215
    (firmware 3.9), which the previous commit flagged as unverified.
    Register test, torque off, id 6 of a calibrated SO-101 arm (originals
    snapshotted and restored):
    config on real STS3215 limits stick accepted goals
    min=0, max=0 yes full +/-30719
    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
2026-07-28 fix(slider-pos): cap slider travel speed so long moves stop tripping overload
    Calibration's drive-to-minimum crawled: fast for ~2s, then roughly 4x
    slower for the rest of the stroke.
    Cause is the servo's overload protection, not a speed setting. With
    Goal_Velocity = 0 the position controller commands full PWM, so
    Present_Load pegs at 1000. Once load stays above Overload_Torque (80%)
    for Protection_Time (~2s), the servo clamps output to Protective_Torque
    (20%) and holds it there. Status bit 5 (overload) confirms the trip.
    Capping the commanded speed keeps PWM under the threshold, so the move
    never trips -- which makes it faster overall. Measured over a 5.7-turn
    stroke on the Jetson rig: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
    [robot.py]
2026-08-11 fix: follow lerobot 0.6 rename of lerobot.types to lerobot.lerobot_types
    lerobot 0.6.0 moved the module; the plugins' imports of RobotAction/
    RobotObservation broke against lerobot==0.6.1. Bump the floor to >=0.6
    since lerobot.lerobot_types does not exist in 0.5.x.
    [robot.py, teleop.py]
